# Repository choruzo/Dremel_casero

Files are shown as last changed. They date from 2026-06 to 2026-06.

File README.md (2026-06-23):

# Dremel casero 🛠️

Adaptador impreso en 3D para convertir un **motor DC 12 V (XD-3420)** en una
herramienta rotativa para **pulir piezas impresas en PLA**.

La pieza conecta la **punta roscada M8** del motor con un **cepillo de pulido de eje
Ø3,7 mm**, usando una **tuerca M8 cautiva** (rosca de acero, no de plástico) y un
**prisionero con inserto M2** para fijar el cepillo.

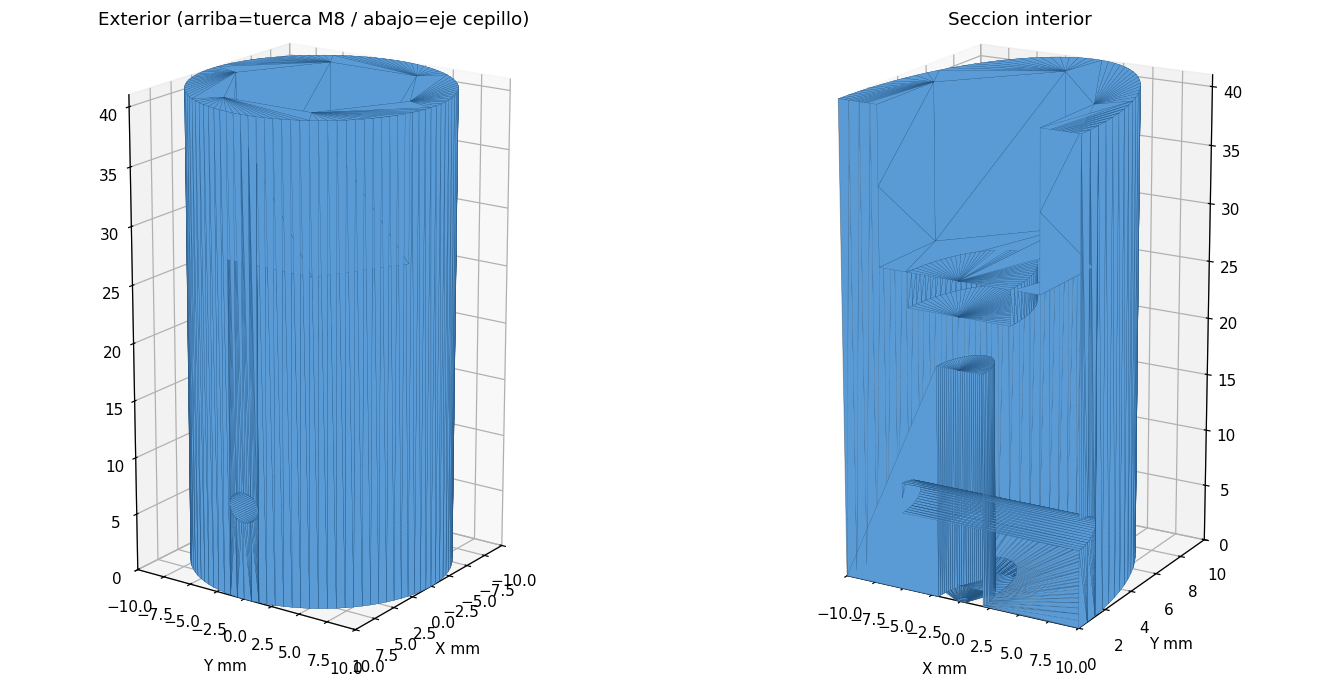
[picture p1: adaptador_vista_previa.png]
Vista previa


---

## Inicio rápido

1. **Imprime** `adaptador_motor_cepillo.stl` — de pie (eje vertical), sin soportes,
   PLA, 3–4 perímetros, 40–60 % de relleno.
2. **Mete la tuerca M8** a presión en el hueco hexagonal.
3. **Enrosca** el adaptador en la punta M8 del motor.
4. **Instala el inserto M2** de latón (calentar y empujar) en el taladro lateral.
5. **Mete el eje del cepillo** y fíjalo con el **tornillo M2×4**.

> ⚠️ Que el motor gire en el sentido que *aprieta* el adaptador (rosca a derechas).
> El PLA reblandece >60 °C: pulir a tirones, sin forzar (o imprimir en PETG).

---

## Necesitas

- Motor XD-3420 (12 V) con punta roscada M8.
- Cepillo de pulido con eje Ø3,7 mm.
- 1–2× tuerca M8 · 1× inserto M2 latón (OD 3,2×3) · 1× tornillo M2×4.

---

## Archivos

| Archivo | Qué es |
|---|---|
| `adaptador_motor_cepillo.stl` | Modelo listo para imprimir (versión actual) |
| `adaptador_motor_cepillo.scad` | Fuente paramétrica para **OpenSCAD** |
| `adaptador.py` / `build_manifold.py` | Fuentes paramétricas en Python |
| `adaptador_vista_previa.png` | Render exterior + sección |
| `adaptador_inserto_M2_cortes.png` | Cortes de verificación del prisionero |
| `HISTORICO_proyecto.md` | **Documentación completa** (specs, parámetros, cambios) |

---

## Personalizar

Edita los parámetros al inicio de `adaptador_motor_cepillo.scad` (Customizer de
OpenSCAD) y exporta el STL con **F6 → Export as STL**. Ajustes más útiles:

- `NUT_CLEAR` — si la tuerca M8 entra floja/justa.
- `SHAFT_FIT` — holgura del eje del cepillo.
- `INSERT_HOLE_D` — agarre del inserto M2 (2,9–3,1).

📄 Detalles completos y registro de cambios en **[`HISTORICO_proyecto.md`](HISTORICO_proyecto.md)**.

---

## Soporte (empuñadura + base 2 en 1)

| Archivo | Qué es |
|---|---|
| `empunadura.stl` / `.scad` | Mango con abrazadera M4 + cola de milano |
| `base.stl` / `.scad` | Base horizontal con dock + bandeja del regulador |
| `empunadura_vista.png`, `base_vista.png` | Renders |

- **Empuñadura:** aprieta el motor con 1× M4 (~30 mm) + 1× tuerca M4. Imprimir de pie.
- **Base:** la empuñadura desliza por la cola de milano hasta el tope. Bandeja superior
  para el regulador (medidas **provisionales**, ajustar). Imprimir con relleno 12–15 %.

- **Tapa del regulador** (`tapa.stl` / `.scad`): se atornilla a la base con 4× inserto
  M2 + tornillo M2×4 avellanado. Imprimir plana. La base ya trae los 4 alojamientos de inserto.

> Si Bambu rellena los huecos al importar mi STL, genera el STL desde OpenSCAD:
> `openscad -o base.stl base.scad`

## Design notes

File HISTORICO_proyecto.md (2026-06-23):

# Dremel casero — Adaptador motor → cepillo de pulido

Proyecto: convertir un motor DC 12 V en una herramienta rotativa tipo Dremel para
**pulir piezas impresas en 3D (PLA)**, mediante una pieza impresa que conecta la punta
roscada del motor con accesorios de pulido de eje fino.

_Última actualización: 2026-06-22_

---

## 1. Componentes de partida

### Motor — XD-3420 (DC, imán permanente)
| Dato | Valor |
|---|---|
| Tensión | 12 V (también admite 24 V) |
| Velocidad sin carga | ~3500 rpm @12 V (≈7000 @24 V) |
| Potencia | ~30 W |
| Eje liso | Ø3 mm |
| **Punta roscada** | **M8 macho, ~13 mm de largo** |
| Extra | agujero transversal en el eje (del diseño original, no se usa aquí) |

Nota: ~3500 rpm es una velocidad **baja**, lo cual es bueno para pulir PLA (menos
riesgo de derretir el plástico por fricción).

### Cepillo de pulido
- Cepillo redondo (cup brush) con **eje central Ø3,7 mm × 42 mm de largo**.

### Tornillería
- **Tuerca M8** estándar (13 mm entre caras) — el usuario ya la tiene.
- **Insertos M2 de latón** termofusibles: OD 3,2 mm × 3 mm de largo (kit 55 uds).
- **Tornillos M2 × 4 mm** (van con los insertos).

---

## 2. Concepto de la solución

No existe un modelo comercial/online que encaje con estas medidas concretas
(M8 → eje 3,7 mm), así que se diseña un **adaptador a medida**.

Estrategia elegida (la más fiable):
- **Lado motor:** alojamiento **hexagonal para una tuerca M8 metálica cautiva**.
  La rosca que aguanta el motor es de **acero**, no de PLA → mucho más resistente.
  La bolsa es profunda (13,5 mm) para alojar **1 o 2 tuercas** (la 2.ª de contratuerca
  contra las vibraciones).
- **Lado cepillo:** taladro para el eje de 3,7 mm + **prisionero lateral** que lo fija.
  Evolución: de prisionero M3 autorroscante en PLA → a **inserto M2 de latón + tornillo
  M2×4** (rosca metálica, más duradera para cambiar de accesorio).

---

## 3. Parámetros del diseño (versión actual)

Archivo paramétrico: `adaptador_motor_cepillo.scad` (OpenSCAD) y `adaptador.py` (Python/trimesh).

| Parámetro | Valor | Descripción |
|---|---|---|
| `OD` | 20 mm | diámetro exterior del cuerpo |
| `L` | 41 mm | longitud total |
| `NUT_AF` | 13 mm | tuerca M8 entre caras (nominal) |
| `NUT_CLEAR` | **−0,10 mm** | → AF efectivo **12,9 mm** (press-fit) |
| `NUT_DEPTH` | 13,5 mm | profundidad bolsa (1–2 tuercas) |
| `CLEAR_BORE_D / _H` | 8,6 / 3 mm | alivio para la punta de rosca del motor |
| `SHAFT_D` | 3,7 mm | eje del cepillo |
| `SHAFT_FIT` | 0,15 mm | → taladro del eje **3,85 mm** |
| `BORE_DEPTH` | 20 mm | profundidad de sujeción del eje |
| `SET_Z` | 8 mm | altura del prisionero desde la base |
| `POCKET_D` | 5,0 mm | avellanado del prisionero |
| `POCKET_FLOOR_R` | 5,7 mm | radio de la cara del inserto (pared efectiva ~3,8 mm) |
| `INSERT_HOLE_D` | 3,0 mm | taladro para inserto M2 (OD 3,2) |
| `INSERT_LEN` | 3,2 mm | longitud inserto + holgura |
| `BOLT_CLEAR_D` | 2,3 mm | paso del tornillo M2 hasta el eje |

Comprobaciones: malla cerrada (`watertight`), pared central entre taladros 4,5 mm,
pared lateral de la tuerca 2,2 mm, la punta del M2×4 alcanza el eje (~0,2 mm de apriete).

---

## 4. Lista de materiales (BOM)

- 1× adaptador impreso (PLA, o PETG si hay calor).
- 1–2× tuerca M8.
- 1× inserto M2 de latón (OD 3,2 × 3 mm).
- 1× tornillo M2×4 (prisionero). *Recomendado tener M2×5/×6 por si falta apriete.*

---

## 5. Impresión

- **Orientación:** de pie (eje Z vertical), boca de la tuerca hacia arriba → sin soportes.
- **Material:** PLA para empezar; **PETG** si se nota reblandecimiento por calor.
- **Perímetros:** 3–4. **Relleno:** 40–60 % (pieza que gira → maciza y equilibrada).
- **Altura de capa:** 0,16–0,20 mm.

---

## 6. Montaje

1. Meter la(s) **tuerca(s) M8** a presión en el hexágono (lado motor).
2. **Enroscar el adaptador** en la punta M8 del motor (apretar a mano).
3. Instalar el **inserto M2** de latón: calentarlo y empujarlo en el taladro Ø3
   (queda hundido dentro del avellanado).
4. **Insertar el eje del cepillo** (Ø3,7) por el otro extremo.
5. Apretar el **tornillo M2×4** contra el eje para fijarlo.

**Sentido de giro:** la rosca es a derechas; asegurarse de que el motor gire en el
sentido que *aprieta* el adaptador. Si gira al revés: invertir polaridad, usar la 2.ª
tuerca de contratuerca, o una gota de fijador de roscas.

**Aviso PLA + calor:** trabajar a tirones, sin forzar; el PLA reblandece >60 °C.

---

## 7. Registro de cambios

- **v0.1** — Diseño inicial. Adaptador M8 (tuerca cautiva) → eje 3,7 mm con prisionero
  M3 autorroscante. STL generado con trimesh.
- **v0.2** — Ajuste tras leer specs reales del motor (rosca M8 de 13 mm): bolsa de
  tuerca a 13,5 mm (cabe 2.ª tuerca de contratuerca), L=41 mm.
- **v0.3** — **Bugfix STL:** el taladro del prisionero atravesaba por completo el eje
  (booleana de trimesh con caras coincidentes → malla no estanca). Reconstruido con
  **manifold3d**: malla limpia y cerrada; prisionero ahora entra por **un solo lado**.
- **v0.4 (actual)** — Tras impresión preliminar OK:
  - Tuerca: `NUT_CLEAR` −0,10 → AF 12,9 mm (press-fit, antes entraba holgada).
  - Prisionero: cambio a **inserto M2 de latón + tornillo M2×4**, con alojamiento
    escalonado (avellanado Ø5 → inserto Ø3 → paso Ø2,3) para que el tornillo corto
    alcance el eje.

---

## 8. Pendiente / ideas futuras

- [ ] Confirmar que la tuerca M8 enrosca bien en la punta del motor (validar que es M8).
- [ ] Probar v0.4 impresa: ajuste del inserto M2 y apriete del tornillo.
- [ ] Afinar `INSERT_HOLE_D` (2,9–3,1) según el agarre del inserto.
- [ ] Valorar tornillo M2×5/×6 si el M2×4 queda corto de apriete.
- [ ] (Opcional) Empuñadura/soporte para sujetar el motor en la mano.
- [ ] (Opcional) Variante con rosca M8 impresa directamente (sin tuerca).

---

## 9. Archivos del proyecto

- `adaptador_motor_cepillo.stl` — modelo listo para imprimir (versión actual).
- `adaptador_motor_cepillo.scad` — fuente paramétrica para OpenSCAD.
- `adaptador.py` — fuente paramétrica en Python (trimesh).
- `build_manifold.py` — generador limpio con manifold3d (referencia).
- `adaptador_vista_previa.png` — render exterior + sección.
- `adaptador_inserto_M2_cortes.png` — cortes de verificación del prisionero.
- `Imagen_motor.png`, `Imagen_motor1.png` — fotos/specs del motor XD-3420.

---

## 10. Soporte: empuñadura + base (2 en 1)

Medidas del motor (calibre del usuario): cuerpo **Ø51 mm × 71 mm**, brida con 2
espárragos **M4 a ~40 mm** (aprox).

**Empuñadura** (`empunadura.stl` / `.scad`):
- Mango tipo barril con **abrazadera (clamp en C)**: aprieta el cuerpo Ø51 con
  **1 tornillo M4 (~30 mm) + 1 tuerca M4** (tuerca cautiva en la orejeta).
- OD ~58 mm, longitud 60 mm. **Cola de milano** inferior para el dock.
- Imprimir de pie, sin soportes.

**Base** (`base.stl` / `.scad`) — uso **horizontal** (tipo pulidora):
- **Cuna + cola de milano hembra**: la empuñadura desliza desde el frente hasta el
  tope trasero; **detente** de retención en el frente (sin herramientas).
- **Bandeja superior** para el regulador PWM (se abre por arriba → imprimible sin
  soportes). **Medidas del hueco PROVISIONALES** (REG_W 54 × REG_H 36 × REG_Yd 40):
  ajustar con las medidas reales del regulador.
- **Canal de cable Ø10** de la bandeja hacia el motor.
- Pieza grande: imprimir con **relleno 12–15 %**.

### Cambios
- **v0.5** — Añadidos empuñadura (clamp M4 + cola de milano) y base horizontal con
  dock de cola de milano + bandeja para regulador (provisional) + canal de cable.

### Pendiente soporte
- [ ] Medidas reales del regulador PWM (ancho × alto × fondo, mando, display, fijación).
- [ ] Validar agarre del clamp M4 y ajuste de la cola de milano tras imprimir.
- [ ] (Opcional) Tapa para la bandeja del regulador; lastre/pie antideslizante.
- **v0.6** — Empuñadura validada impresa (medidas OK). Bandeja del regulador ajustada
  a medidas reales: placa ~40×30, mando Ø20 (muesca en pared trasera), comp. ~13 mm;
  cavidad 44×34×20 mm con bajada de cable al canal hacia el motor.
- **v0.7** — Añadida TAPA para la bandeja del regulador (`tapa.stl`/`.scad`): plancha
  70×42×3 con 4 avellanados M2 y muesca para el cable de alimentación. La base
  incorpora 4 alojamientos de **inserto M2** (Ø3, prof. 4) en el borde de las paredes;
  fijación con tornillo **M2×4 avellanado**. Recordatorio Bambu: exportar STL desde
  OpenSCAD (`openscad -o pieza.stl pieza.scad`) para evitar el relleno de huecos.

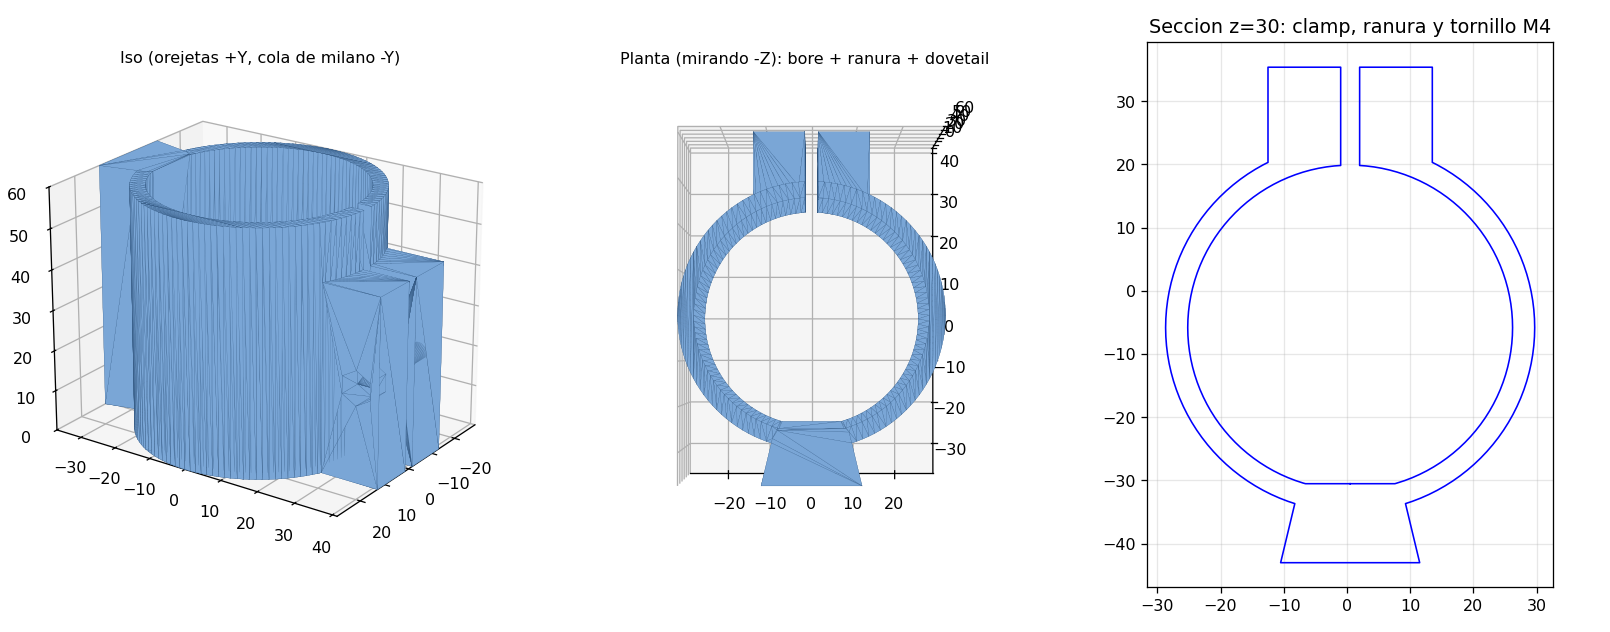
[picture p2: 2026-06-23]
empunadura_vista.png

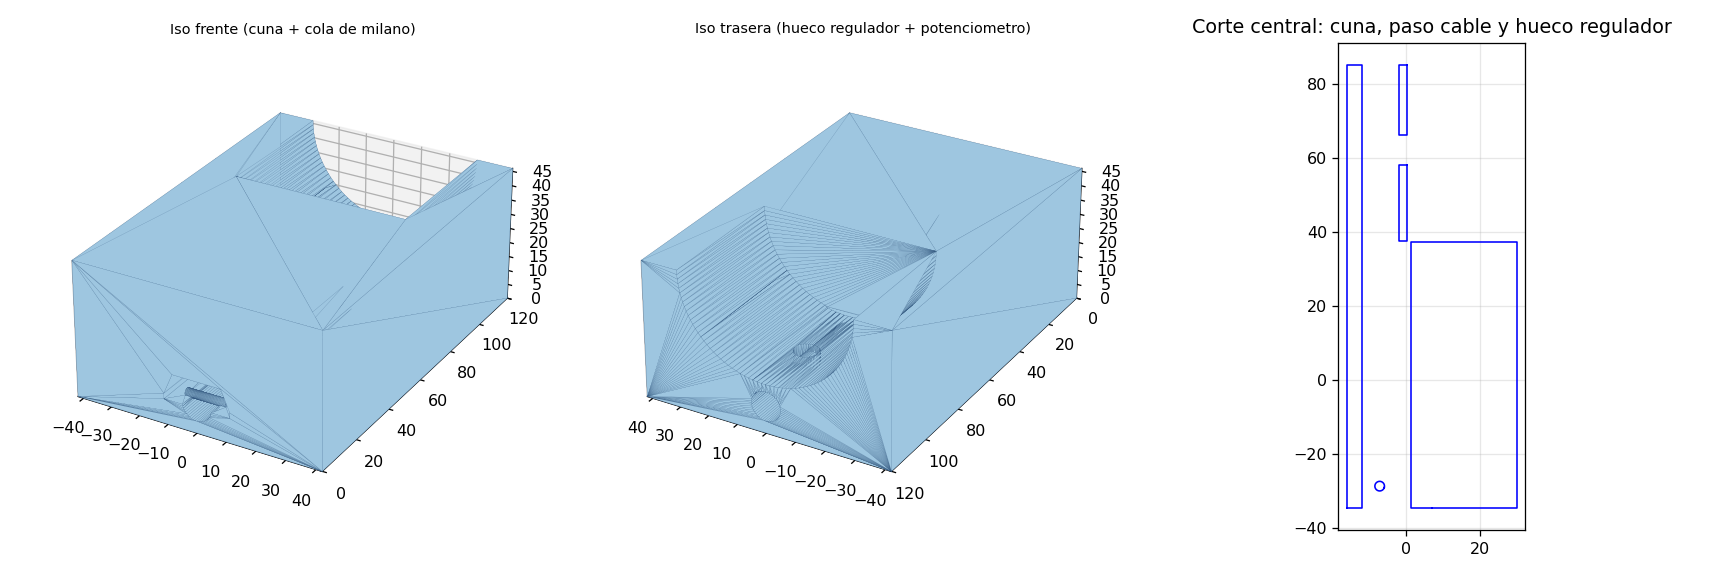
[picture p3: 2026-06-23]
base_vista.png

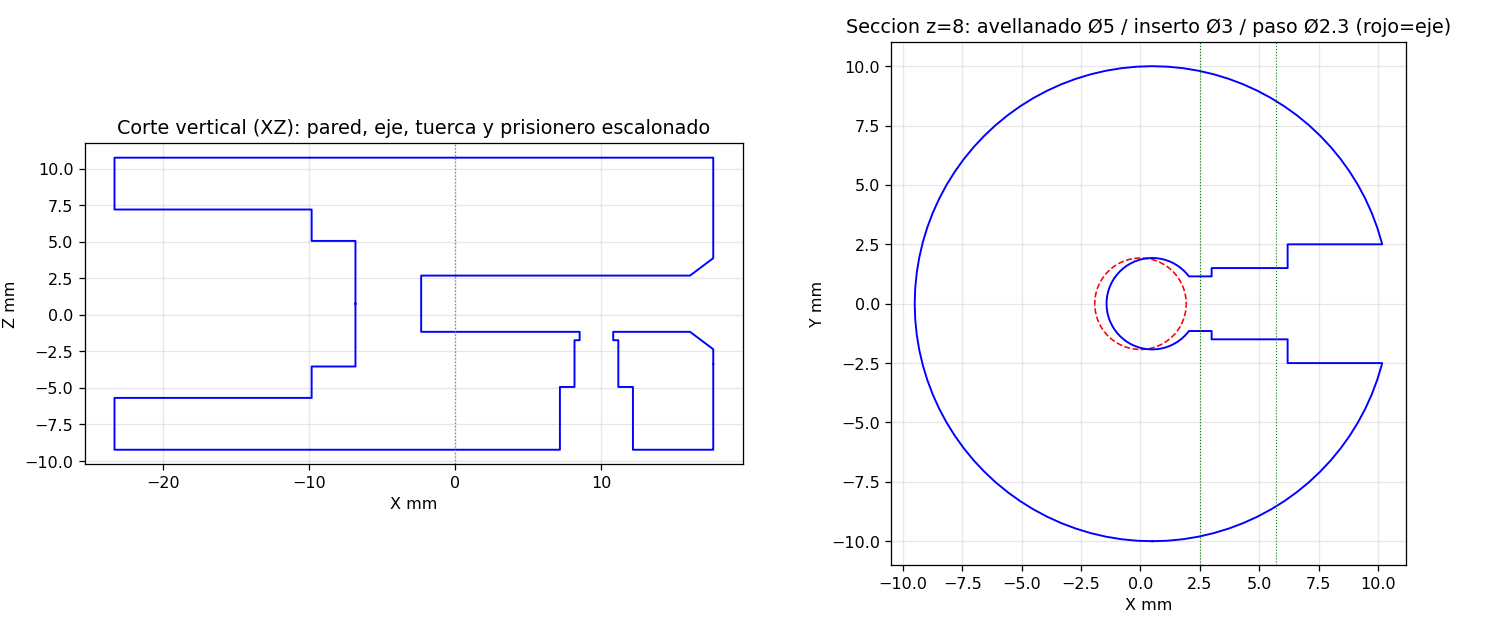
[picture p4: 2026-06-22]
adaptador_inserto_M2_cortes.png

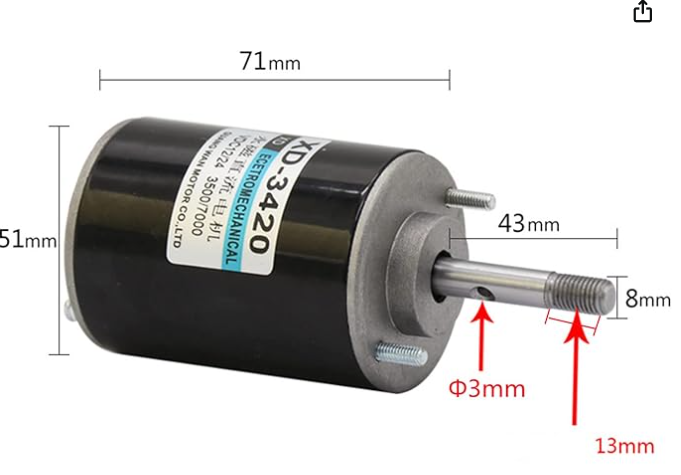
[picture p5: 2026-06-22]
Imagen_motor.png

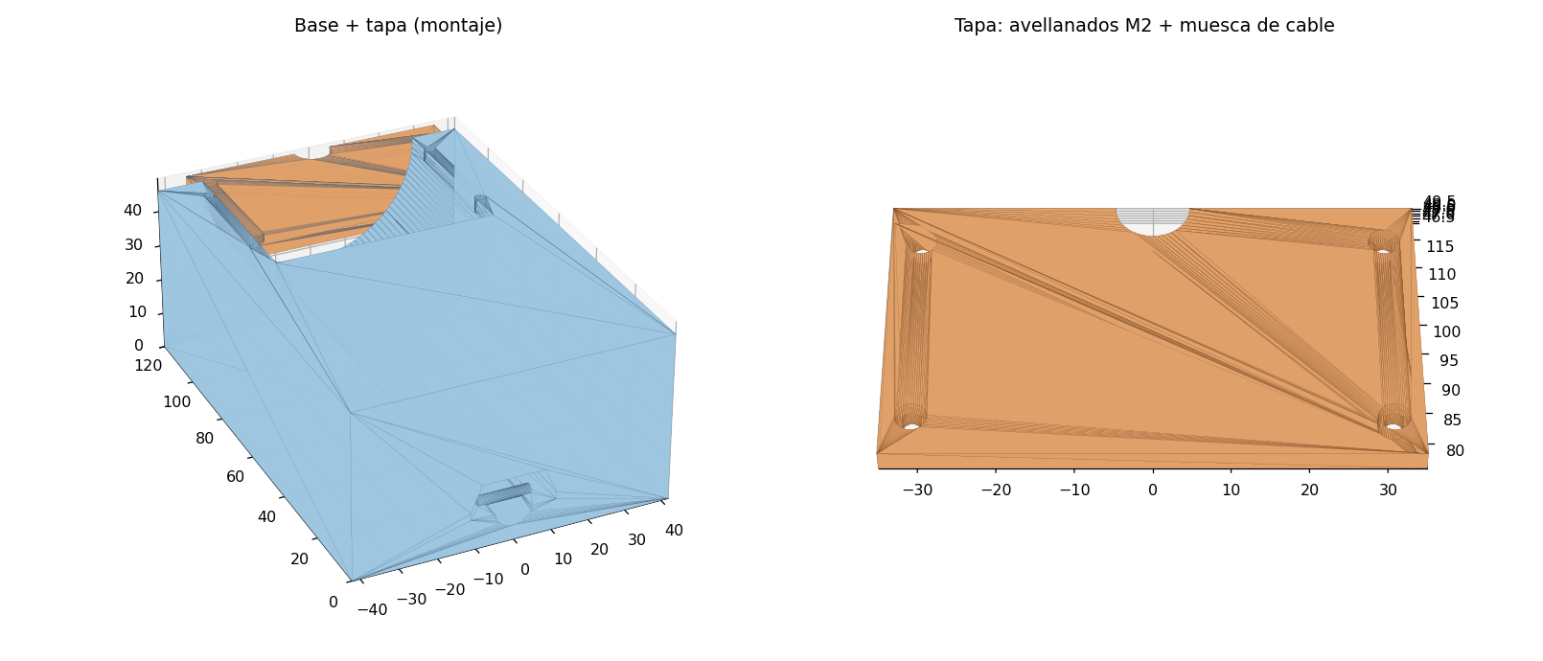
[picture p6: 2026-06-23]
tapa_vista.png

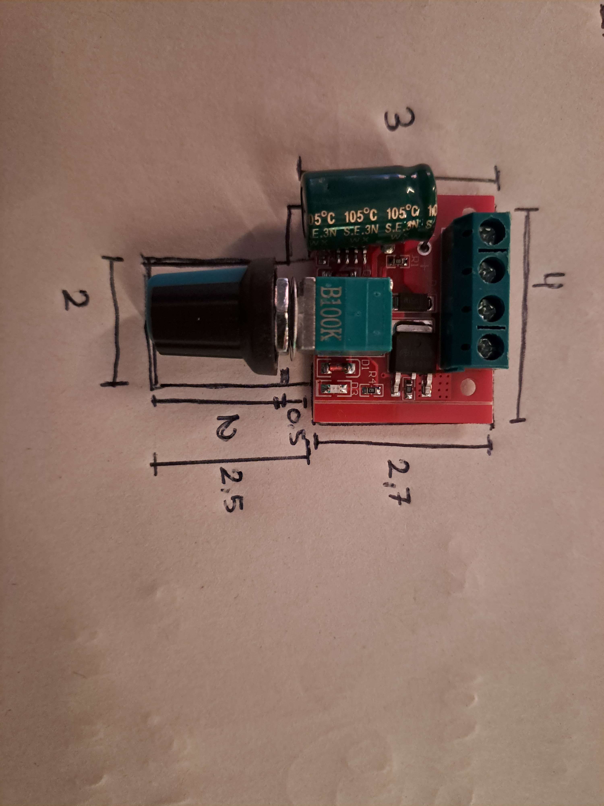
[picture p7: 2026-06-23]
regulador_corriente.jpg

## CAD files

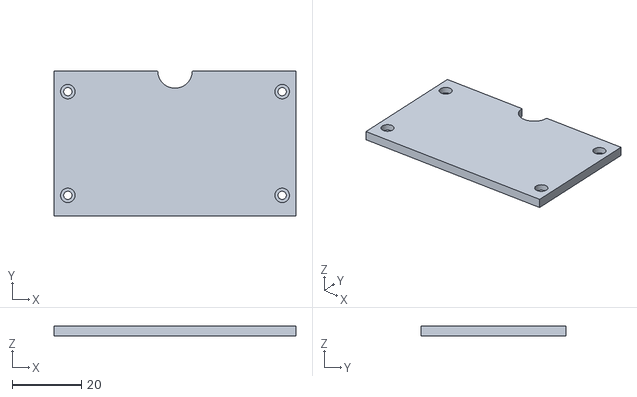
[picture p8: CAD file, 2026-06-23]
tapa.stl
70.0 x 42.0 x 3.00

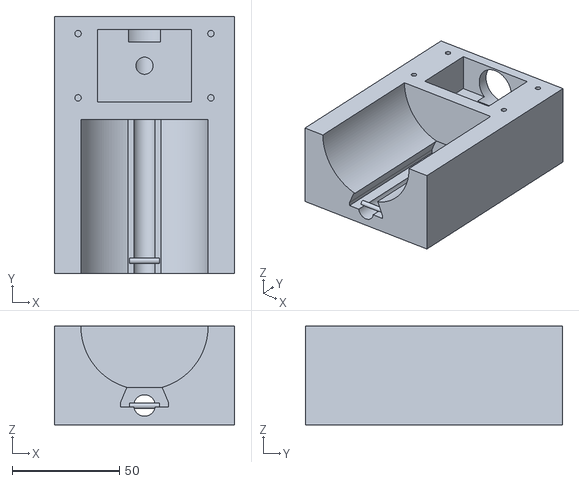
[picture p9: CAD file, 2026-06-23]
base_1.stl
84.0 x 120.0 x 46.0

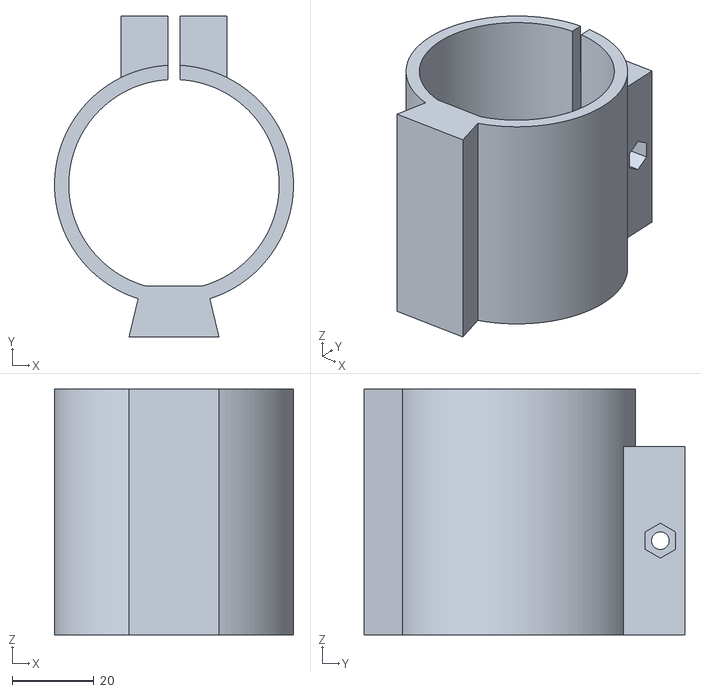
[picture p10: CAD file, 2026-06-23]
empunadura.stl
58.4 x 78.4 x 60.0

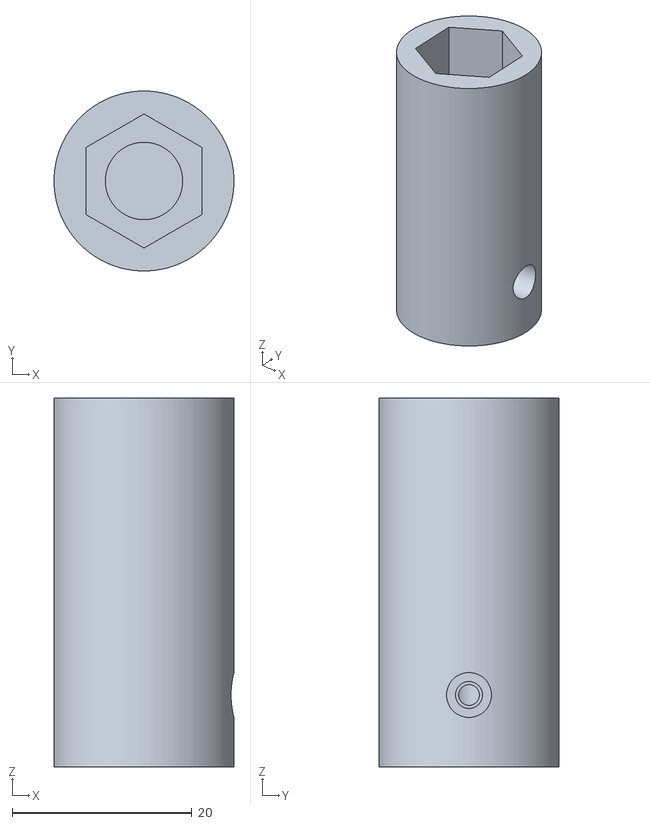
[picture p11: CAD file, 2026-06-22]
adaptador_motor_cepillo.stl
20.0 x 20.0 x 41.0

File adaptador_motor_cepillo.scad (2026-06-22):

// =====================================================================
//  Adaptador motor XD-3420 (punta roscada M8) -> cepillo de pulido
//  Lado motor:  bolsa hexagonal para 1 o 2 TUERCAS M8 (press-fit)
//  Lado cepillo: taladro eje 3,7 mm + INSERTO M2 de laton + tornillo M2x4
//  Imprimir DE PIE (eje Z), sin soportes.
// =====================================================================

/* [Cuerpo] */
OD            = 20;     // diametro exterior (mm)
L             = 41;     // longitud total (mm)

/* [Lado motor - tuerca M8] */
NUT_AF        = 13;     // tuerca M8 entre caras (mm)
NUT_CLEAR     = -0.10;  // AJUSTADO: AF efectivo 12.9 (press-fit). Sube si no entra.
NUT_DEPTH     = 13.5;   // 13.5 = caben 2 tuercas (la 2a de contratuerca)
CLEAR_BORE_D  = 8.6;    // alivio para la punta de la rosca del motor
CLEAR_BORE_H  = 3;

/* [Lado cepillo - eje 3,7 mm] */
SHAFT_D       = 3.7;
SHAFT_FIT     = 0.15;   // holgura del taladro del eje
BORE_DEPTH    = 20;

/* [Prisionero - inserto M2 laton OD3.2 x 3 + tornillo M2x4] */
SET_Z          = 8;     // altura del prisionero desde la base
POCKET_D       = 5.0;   // avellanado (acerca el inserto al eje y da paso al util)
POCKET_FLOOR_R = 5.7;   // radio de la cara del inserto (pared efectiva ~3.8 mm)
INSERT_HOLE_D  = 3.0;   // taladro para el inserto termofusible (OD 3.2)
INSERT_LEN     = 3.2;   // longitud inserto + holgura
BOLT_CLEAR_D   = 2.3;   // paso libre del tornillo M2 hasta el eje

/* [Calidad] */
$fn = 120;

BORE_D   = SHAFT_D + SHAFT_FIT;
hex_circ = ((NUT_AF + NUT_CLEAR)/2) / cos(30);

module nut_pocket(){
    translate([0,0,L-NUT_DEPTH]) rotate([0,0,30])
        cylinder(r=hex_circ, h=NUT_DEPTH+1, $fn=6);
}
module clear_bore(){
    translate([0,0,L-NUT_DEPTH-CLEAR_BORE_H])
        cylinder(d=CLEAR_BORE_D, h=CLEAR_BORE_H+1);   // solapa 1mm en la bolsa
}
module brush_bore(){
    translate([0,0,-1]) cylinder(d=BORE_D, h=BORE_DEPTH+1);
    translate([0,0,-0.01]) cylinder(d1=BORE_D+2.4, d2=BORE_D, h=1.5); // avellanado entrada
}
module setscrew_insert(){
    translate([0,0,SET_Z]) rotate([0,90,0]){   // +Z local -> +X global
        translate([0,0,POCKET_FLOOR_R])
            cylinder(d=POCKET_D, h=OD/2+0.6-POCKET_FLOOR_R);          // avellanado Ø5
        translate([0,0,POCKET_FLOOR_R-INSERT_LEN])
            cylinder(d=INSERT_HOLE_D, h=INSERT_LEN+0.01);             // taladro inserto Ø3
        translate([0,0,-0.5])
            cylinder(d=BOLT_CLEAR_D, h=POCKET_FLOOR_R-INSERT_LEN+0.5);// paso tornillo Ø2.3
    }
}

difference(){
    cylinder(d=OD, h=L);
    nut_pocket();
    clear_bore();
    brush_bore();
    setscrew_insert();
}

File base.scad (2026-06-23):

// =====================================================================
//  Base 2-en-1 para la empuñadura del Dremel casero (uso horizontal)
//  - Cuna + cola de milano HEMBRA (desliza desde el frente al tope).
//  - Bandeja superior para el regulador PWM (medidas reales del usuario).
//  - Muesca para el mando + canal de cable hacia el motor.
//  Imprimir con la base apoyada (Z arriba), sin soportes. Relleno 12-15%.
// =====================================================================

/* [Empuñadura / cuna] */
ROUT = 29.2; CR = 29.7; Zc = 46;

/* [Base] */
BW = 84; BD = 120; BH = 46;

/* [Cola de milano hembra] */
CRADLE_Y0 = -5; CRADLE_Y1 = 72;
DT_TOP_W = 16.6; DT_BOT_W = 22.6; DTz_bot = 8.3; DTz_top = 17.3;

/* [Regulador PWM] (medidas reales) */
REG_X = 44;     // ancho de la bandeja (placa ~40 + holgura)
REG_Y = 34;     // fondo de la bandeja (~30 + holgura)
REG_DEPTH = 20; // alto util (componentes ~13 mm)
KNOB_D = 20;    // diametro del mando
KNOB_CL = 2;    // holgura de la muesca
KNOB_Z = 8;     // altura del eje del mando sobre el suelo de la bandeja

$fn = 128;
reg_yc = BD-6-REG_Y/2; reg_floor = BH-REG_DEPTH;

module base(){
  difference(){
    translate([-BW/2,0,0]) cube([BW,BD,BH]);
    translate([0,CRADLE_Y0,Zc]) rotate([-90,0,0]) cylinder(r=CR, h=CRADLE_Y1-CRADLE_Y0);
    hull(){
      translate([0,(CRADLE_Y0-1+CRADLE_Y1)/2,(DTz_bot+10.2)/2])
        cube([DT_BOT_W, CRADLE_Y1-CRADLE_Y0+2, 10.2-DTz_bot], center=true);
      translate([0,(CRADLE_Y0-1+CRADLE_Y1)/2,(12.8+DTz_top)/2])
        cube([DT_TOP_W, CRADLE_Y1-CRADLE_Y0+2, DTz_top-12.8], center=true);
    }
    // bandeja del regulador (abre arriba)
    translate([0,reg_yc, BH-REG_DEPTH/2+1]) cube([REG_X,REG_Y,REG_DEPTH+2],center=true);
    // muesca del mando (sale por la pared trasera)
    translate([0,BD-12,reg_floor+KNOB_Z]) rotate([-90,0,0]) cylinder(r=(KNOB_D+KNOB_CL)/2, h=16);
    // canal de cable + bajada vertical
    translate([0,0,9]) rotate([-90,0,0]) cylinder(r=5, h=BD);
    translate([0,reg_yc,9]) cylinder(r=4, h=REG_DEPTH+2);
    // 4 alojamientos para insertos M2 (tapa)
    for(p=[[-31,82],[31,82],[-31,112],[31,112]])
        translate([p[0],p[1],BH-4]) cylinder(d=3.0, h=5, $fn=48);
  }
}
base();

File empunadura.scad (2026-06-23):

// =====================================================================
//  Empuñadura (mango barril con abrazadera) para motor XD-3420
//  Sujeta el cuerpo Ø51 mm apretando un tornillo M4 (clamp tipo C).
//  Cola de milano inferior -> encaja deslizando en la base (2 en 1).
//  Imprimir DE PIE (eje Z), sin soportes.
// =====================================================================

/* [Motor] */
MOTOR_D = 51;     // diametro del cuerpo del motor (mm)
FIT     = 0.4;    // holgura del clamp (lo cierra el tornillo)

/* [Mango] */
WALL    = 3.5;    // espesor de pared
LEN     = 60;     // longitud del mango

/* [Abrazadera] */
SLIT    = 3;      // ancho de la ranura de la C
EAR_X   = 11.5;   // ancho de cada orejeta
EAR_OUT = 12;     // cuanto sobresalen las orejetas
EAR_Z0  = 0;      // base de las orejetas (0 = sin voladizo)
EAR_Z1  = 46;     // alto de las orejetas
M4_CLEAR = 4.3;   // paso del tornillo M4
M4_NUT_AF = 7;    // tuerca M4 entre caras
M4_NUT_CL = 0.4;

/* [Cola de milano - dock] */
DT_TOP_W = 16;    // ancho en la raiz
DT_BOT_W = 22;    // ancho en la punta (mas ancho = bloquea)
DT_H     = 8;     // altura

$fn = 128;

RIN  = (MOTOR_D+FIT)/2;
ROUT = RIN + WALL;
BOLT_Y = ROUT + 6;
BOLT_Z = (EAR_Z0+EAR_Z1)/2;

module body(){
    difference(){
        cylinder(r=ROUT, h=LEN);
        translate([0,0,-1]) cylinder(r=RIN, h=LEN+2);
    }
}
module ears(){
    for(s=[-1,1])
        translate([s*(SLIT/2+EAR_X/2), (RIN+ROUT+EAR_OUT)/2, (EAR_Z0+EAR_Z1)/2])
            cube([EAR_X, (ROUT+EAR_OUT)-RIN, EAR_Z1-EAR_Z0], center=true);
}
module dovetail(){
    linear_extrude(LEN)
        polygon([[-DT_BOT_W/2,-(ROUT+DT_H)],[DT_BOT_W/2,-(ROUT+DT_H)],
                 [DT_TOP_W/2,-RIN+1],[-DT_TOP_W/2,-RIN+1]]);
}
module cuts(){
    // ranura de la C
    translate([0,(RIN-2+ROUT+EAR_OUT+5)/2, LEN/2])
        cube([SLIT,(ROUT+EAR_OUT+5)-(RIN-2),LEN+4],center=true);
    // tornillo M4: paso desde -X
    translate([0,BOLT_Y,BOLT_Z]) rotate([0,90,0])
        translate([0,0,-(ROUT+EAR_OUT+1)])
            cylinder(d=M4_CLEAR, h=(ROUT+EAR_OUT+1)+(SLIT/2+EAR_X));
    // tuerca M4 cautiva en la orejeta +X
    translate([0,BOLT_Y,BOLT_Z]) rotate([0,90,0])
        translate([0,0,(SLIT/2+EAR_X)-EAR_X*0.55])
            cylinder(r=(M4_NUT_AF+M4_NUT_CL)/2/cos(30), h=EAR_X*0.55+0.1, $fn=6);
}
difference(){
    union(){ body(); ears(); dovetail(); }
    cuts();
}

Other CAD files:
base.3mf
tapa.scad
base.stl

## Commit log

2026-06-23 Add README.md for 3D printed Dremel adapter instructions and details
2026-06-23 Add empuñadura and base designs, including support for PWM regulator and new tapa
    [base.3mf, base.scad, base.stl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]
